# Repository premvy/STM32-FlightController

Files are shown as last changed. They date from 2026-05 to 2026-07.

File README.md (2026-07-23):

# ⚡️Custom STM32  Flight Controller

## Description 
This project is a custom designed, two layer flight controller built to serve as the central brain for a drone prototype. The board is driven by an STM32F722RET6 microcontroller, providing the high-speed processing headroom required for low latency PID loops. The hardware stack features an ICM-42688 6-axis IMU, a BMP580 barometer for precision altitude hold, and a dedicated microSD slot for high rate Blackbox data logging. Power delivery is managed through a modern USB-C interface, paired with a BQ series battery management IC and a clean 5V buck-boost circuit to safely drive servos and ESCs. Beyond just getting a vehicle in the air, this board was designed to push a concept from a raw schematic into a fully manufactured physical product.

## PCB design 





_Custom PCB routed in Kicad_

## Schematic



**Hardware Specs:**
* **MCU:** STM32F722RETx clocked by a 25MHz external crystal.
* **Sensors:** ICM-42688 (6-axis IMU) and BMP580 (Barometer).
* **Power:** USB-C connectivity, BQ-series battery charging, a clean 3.3V logic rail, and a 5V buck-boost rail for servos and ESCs.
* **Data Logging:** Dedicated 4-bit microSD slot for high-speed flight recording.
* **I/O:** 3-pin PWM motor headers and hardware `BOOT` / `RESET` buttons.

[View the Bill of Materials (BOM)](./production/bom.md)

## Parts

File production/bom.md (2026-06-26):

## Bill of Materials

| Designator | Footprint | Qty | Value | LCSC Part # | Unit Price (USD) | Ext. Price (USD) |
|---|---|---|---|---|---|---|
| C1, C29, C30, C31 | 0402 | 4 | 1uF | C52923 | 0.005 | 0.02 |
| C10, C16, C19, C20, C21, C22, C24, C25, C26, C27, C37 | 0201 | 11 | 100nF | C76934 | 0.002 | 0.02 |
| C11, C2, C6, C9 | 0603 | 4 | 10uF | C19702 | 0.016 | 0.06 |
| C12, C13, C14 | 0805 | 3 | 22uF | C45783 | 0.058 | 0.18 |
| C15 | 0603 | 1 | 2.2uF | C23630 | 0.009 | 0.01 |
| C17, C18 | 0402 | 2 | 22uF | C415703 | 0.088 | 0.18 |
| C23 | 0201 | 1 | 2.2uF | C318539 | 0.014 | 0.01 |
| C28 | 0402 | 1 | 100nF | C1525 | 0.002 | 0.01 |
| C3 | 0402 | 1 | 44uF* | C19702 | 0.016 | 0.02 |
| C32, C4 | 0201 | 2 | 10uF | (DigiKey) | 0.020 | 0.04 |
| C33, C34 | 0201 | 2 | 20pF | C325444 | 0.002 | 0.01 |
| C35, C36 | 0201 | 2 | 6.8pF | C85916 | 0.002 | 0.01 |
| C5 | 0402 | 1 | 47nF | C82219 | 0.003 | 0.01 |
| C7, C8 | 0805 | 2 | 10uF | C440198 | 0.038 | 0.08 |
| CARD1 | TF-SMD_TF-01A | 1 | TF-01A microSD | C91145 | 0.190 | 0.19 |
| D1 | 0402 | 1 | LED | C965793 | 0.008 | 0.01 |
| J1 | TerminalBlock 2P P2.54mm | 1 | Screw Terminal | (DigiKey 282834-2) | 1.870 | 1.87 |
| J2, J3 | PinHeader 1x03 P2.54mm | 2 | Conn_01x03 | (DigiKey) | 0.100 | 0.20 |
| L1 | L2520 | 1 | 1uH | C435392 | 0.450 | 0.45 |
| L2 | IND-SMD L4.0xW4.0 | 1 | 1.5uH | C3033018 | 1.370 | 1.37 |
| L3 | IND-SMD L3.0xW3.0 | 1 | 5.6uH | C18236327 | 0.560 | 0.56 |
| L4 | L0603 | 1 | 600R ferrite | C141723 | 0.150 | 0.15 |
| R1, R2 | 0201 | 2 | 5.1k | C270344 | 0.001 | 0.01 |
| R10 | 0201 | 1 | 383 | (DigiKey) | 0.034 | 0.03 |
| R11, R12, R13, R16-R22, R3-R7 | 0201 | 15 | 10K | C7467266 | 0.001 | 0.02 |
| R14 | 0402 | 1 | 100K | C25741 | 0.005 | 0.01 |
| R15 | 0201 | 1 | 22.1K | C384418 | 0.010 | 0.01 |
| R8 | 0201 | 1 | 5.23K | C332546 | 0.011 | 0.01 |
| R9 | 0201 | 1 | 30.1K | (DigiKey) | 0.034 | 0.03 |
| SW1, SW2 | SW-SMD L3.9xW3.0 | 2 | TS-1088-AR02016 | C720477 | 0.120 | 0.24 |
| U1 | LGA-10 BMP580 | 1 | BMP580 baro | C22391138 | 2.500 | 2.50 |
| U2 | LQFP-64 | 1 | STM32F722RETx | C118207 | 4.160 | 4.16 |
| U3 | LGA-14 | 1 | ICM-45686 IMU | C22459454 | 9.760 | 9.76 |
| U4 | VQFN-15 | 1 | TPS63070RNMR | C109322 | 3.500 | 3.50 |
| U5 | VFQFPN-24 | 1 | BQ25883RGER | C544362 | 2.800 | 2.80 |
| U6 | SOT-23-6 | 1 | LMR51430 | C5219261 | 0.550 | 0.55 |
| USB1 | USB-C 16P 2MD | 1 | Type-C | C2765186 | 0.400 | 0.40 |
| X1 | CRYSTAL-SMD 4P | 1 | X322525MOB4SI 25MHz | C9006 | 0.350 | 0.35 |
| X2 | FC-135R | 1 | Q13FC1350000400 32.768kHz | C32346 | 0.300 | 0.30 |
| | | | | | **Component subtotal** | **30.43** |

## Full Prototype Cost (JLCPCB)

- **PCB:** $18.46
- **PCBA: $154.29**, broken into:
  - Setup fee: $25.56
  - Stencil: $8.21
  - Components (32): $62.66
  - Feeder loading: $48.96
  - SMT assembly: $1.85
  - X-ray inspection: $6.56
  - Packaging: $0.49
- **Total: $172.75** (before shipping &rarr; ~$200 delivered)

> **Note on scaling:** This is a run cost, not a per-unit cost. Roughly **$82.73** of the total is one-time non-recurring setup &mdash; setup fee ($25.56), stencil ($8.21), and feeder loading ($48.96) &mdash; which does not repeat on follow-up orders. The two-board minimum is why the $62.66 component line is ~2x the $30.43 per-board BOM subtotal above. The marginal cost of additional boards is substantially lower once the line is set up.

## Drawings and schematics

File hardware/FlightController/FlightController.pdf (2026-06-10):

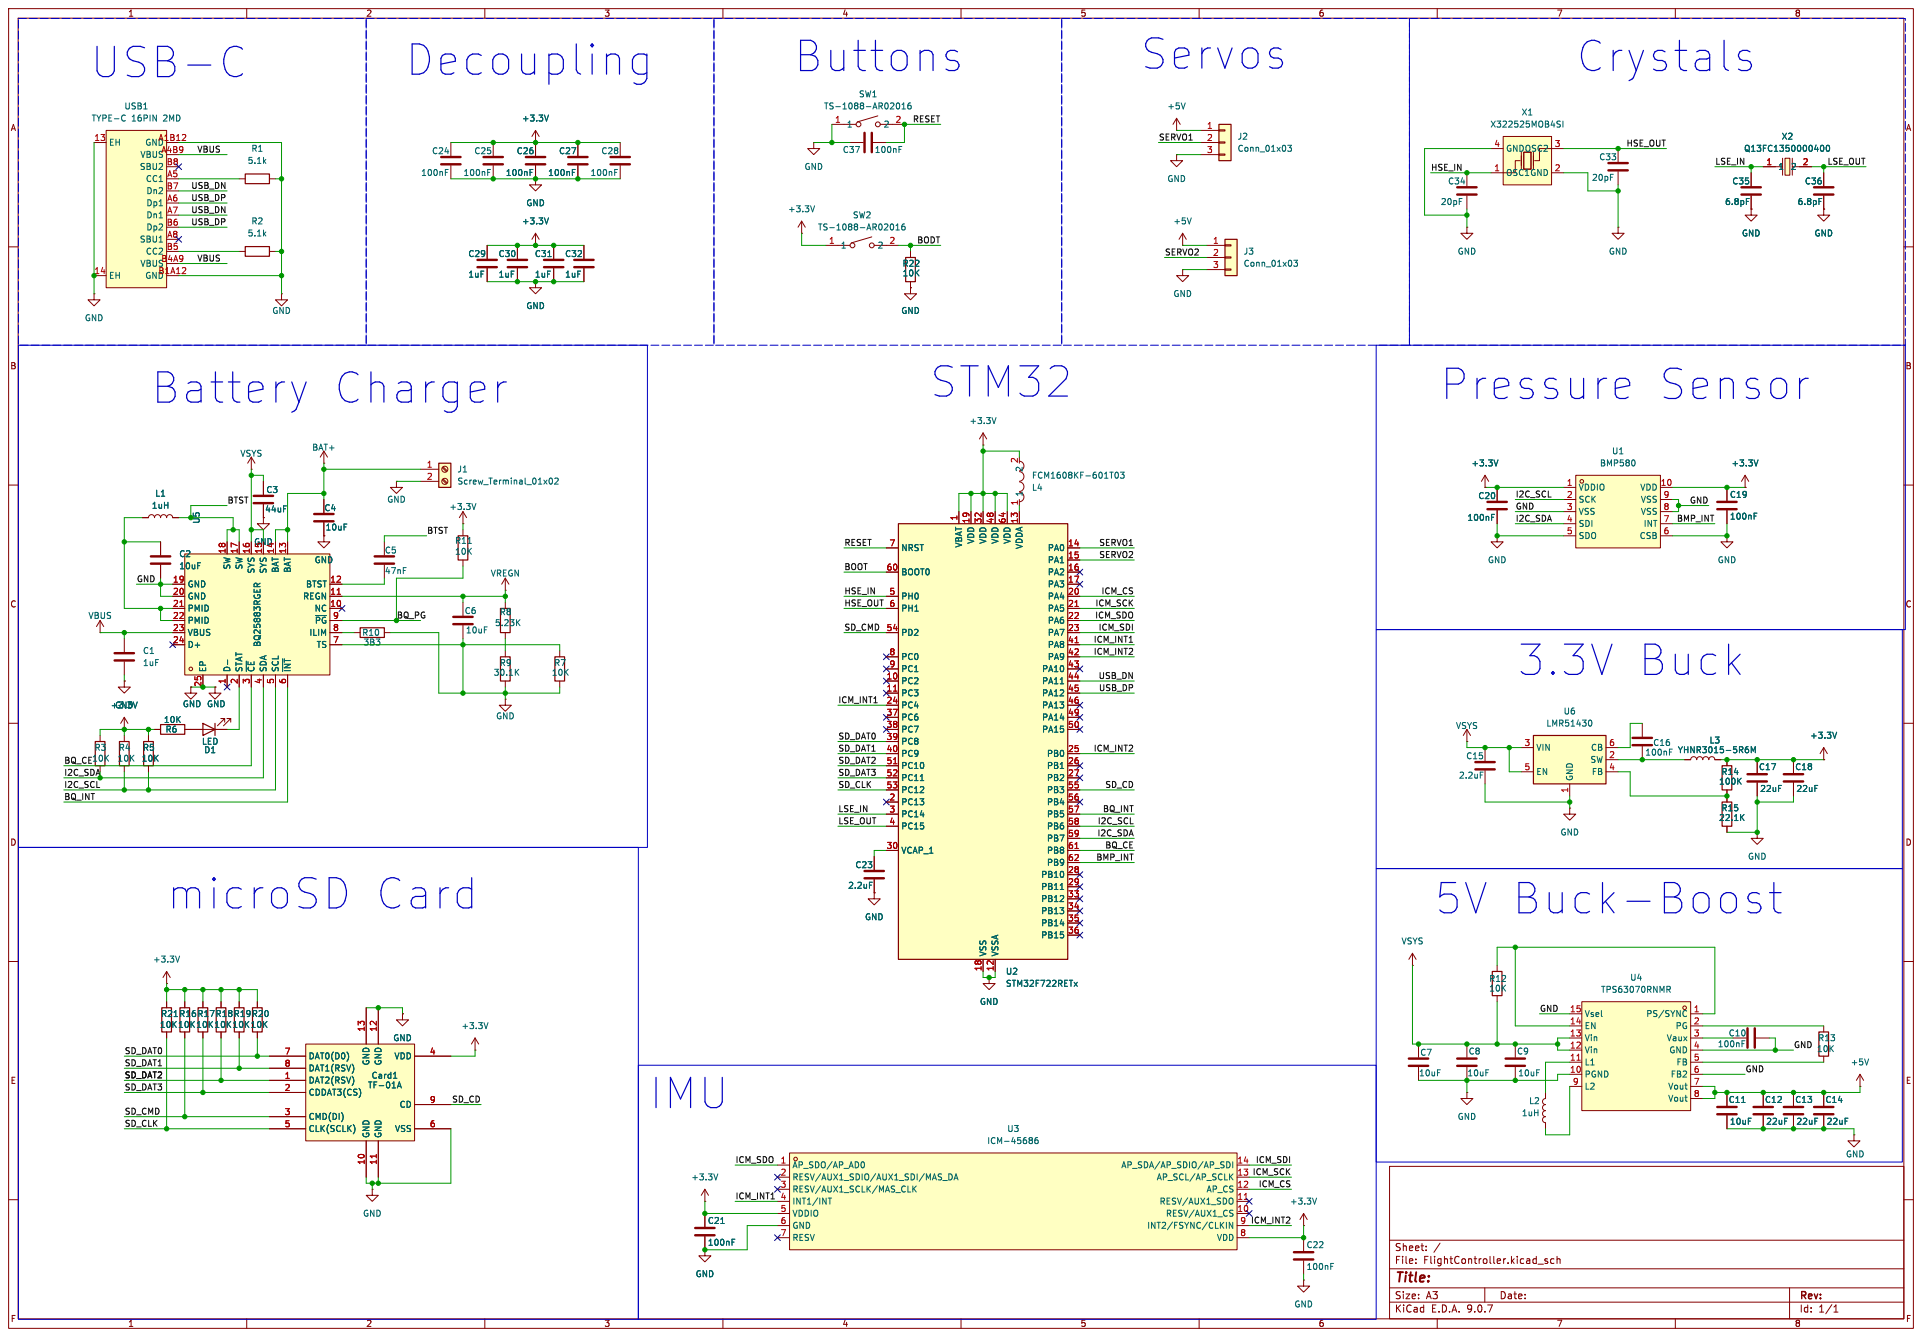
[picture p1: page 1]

5 ~{INT} 6 D+ 24 TS 7 VBUS 23 ILIM 8 PMID 22 ~{PG}9 PMID 21 NC 10 GND 20 REGN 11 GND 19 BTST 12 SW 18 SW 17 SYS 16 SYS 15 BAT 14 BAT 13 U5 BQ25883RGER GND GND

1 VDD 19 VDD 32 VSS 18 VDD 48 VSSA 12 VDD 64 VDDA 13 PA0 14 PA1 15 PA2 16 PA3 17 PA4 20 PA5 21 PA6 22 PA7 23 PA8 41 PA9 42 PA10 43 PA11 44 PA12 45 PA13 46 PA14 49 PA15 50 PB0 25 PB1 26 PB2 27 PB3 55 PB4 56 PB5 57 PB6 58 PB7 59 PB8 61 PB9 62 PB10 28 PB11 29 PB12 33 PB13 34 PB14 35 PB15 36 GND

1 VDD 19 VDD 32 VSS 18 VDD 48 VSSA 12 VDD 64 VDDA 13 PA0 14 PA1 15 PA2 16 PA3 17 PA4 20 PA5 21 PA6 22 PA7 23 PA8 41 PA9 42 PA10 43 PA11 44 PA12 45 PA13 46 PA14 49 PA15 50 PB0 25 PB1 26 PB2 27 PB3 55 PB4 56 PB5 57 PB6 58 PB7 59 PB8 61 PB9 62 PB10 28 PB11 29 PB12 33 PB13 34 PB14 35 PB15 36 U2STM32F722RETx VSYS

5 ~{INT} 6 D+ 24 TS 7 VBUS 23 ILIM 8 PMID 22 ~{PG}9 PMID 21 NC 10 GND 20 REGN 11 GND 19 BTST 12 SW 18 SW 17 SYS 16 SYS 15 BAT 14 BAT 13 GND C2
VSYS C2

6 Vout 7 Vout 8 Vsel 15 EN 14 Vin 13 Vin 12

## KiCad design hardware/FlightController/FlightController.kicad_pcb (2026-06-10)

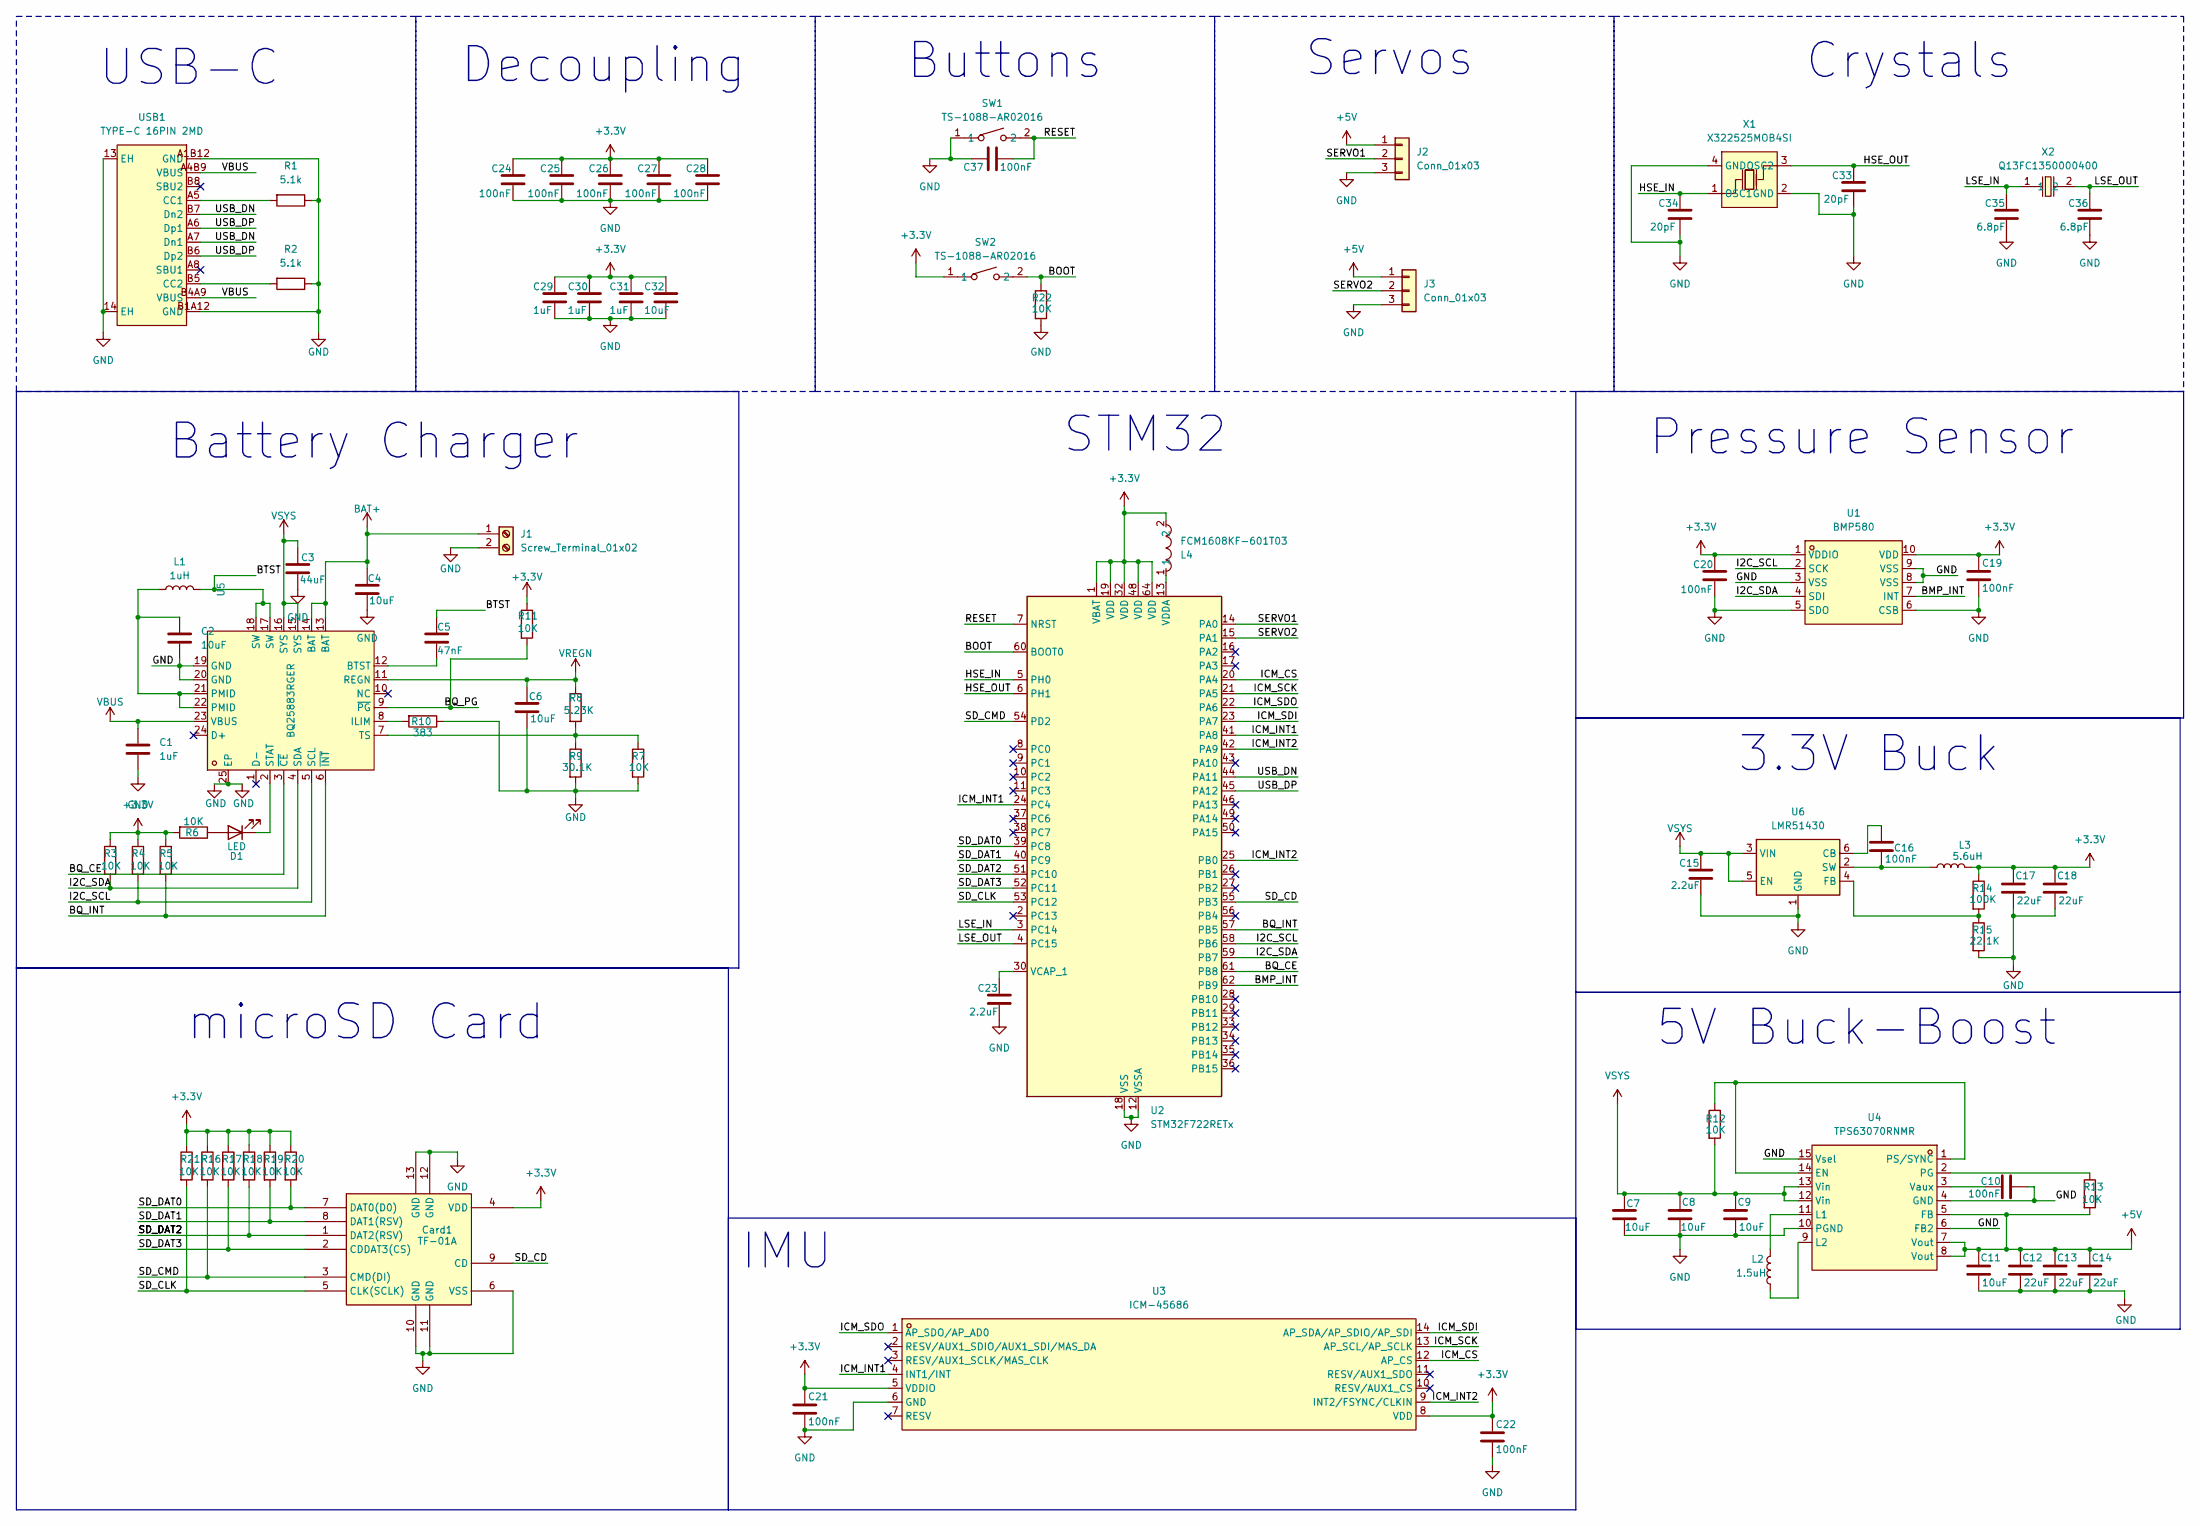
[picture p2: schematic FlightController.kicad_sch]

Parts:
C1, C29, C30, C31: 1uF; C_0402_1005Metric
C2, C6, C9, C11: 10uF; C_0603_1608Metric
C3: 44uF; C_0402_1005Metric
C4, C32: 10uF; C_0201_0603Metric
C5: 47nF; C_0402_1005Metric
C7, C8: 10uF; C_0805_2012Metric
C10, C16, C19, C20, C21, C22, C24, C25, C26, C27, C37: 100nF; C_0201_0603Metric
C12, C13, C14: 22uF; C_0805_2012Metric
C15: 2.2uF; C_0603_1608Metric
C17, C18: 22uF; C_0402_1005Metric
C23: 2.2uF; C_0201_0603Metric
C28: 100nF; C_0402_1005Metric
C33, C34: 20pF; C_0201_0603Metric
C35, C36: 6.8pF; C_0201_0603Metric
Card1: TF-01A; TF-SMD_TF-01A; MPN TF-01A; LCSC Part C91145
D1: LED; LED_0402_1005Metric
J1: Screw_Terminal_01x02; TerminalBlock_Xinya_XY308-2.54-2P_1x02_P2.54mm_Horizontal
J2, J3: Conn_01x03; PinHeader_1x03_P2.54mm_Vertical
L1: 1uH; L2520
L2: 1.5uH; IND-SMD_L4.0-W4.0-A
L3: 5.6uH; IND-SMD_L3.0-W3.0
L4: FCM1608KF-601T03; L0603; MPN FCM1608KF-601T03; LCSC Part C141723
R1, R2: 5.1k; R_0201_0603Metric
R3, R4, R5, R6, R7, R11, R12, R13, R16, R17, R18, R19, R20, R21, R22: 10K; R_0201_0603Metric
R8: 5.23K; R_0201_0603Metric
R9: 30.1K; R_0201_0603Metric
R10: 383; R_0201_0603Metric
R14: 100K; R_0402_1005Metric
R15: 22.1K; R_0201_0603Metric
SW1, SW2: TS-1088-AR02016; SW-SMD_L3.9-W3.0-P4.45; MPN TS-1088-AR02016; LCSC Part C720477
U1: BMP580; LGA-10_L2.0-W2.0-P0.50-TL_BMP580; MPN BMP580; LCSC Part C22391138
U2: STM32F722RETx; LQFP-64_10x10mm_P0.5mm
U3: ICM-45686; LGA-14_L3.0-W2.5-P0.50-TL; MPN ICM-45686; LCSC Part C22459454
U4: TPS63070RNMR; VQFN-15_L3.0-W2.5-P0.50-BL; MPN TPS63070RNMR; LCSC Part C109322
U5: BQ25883RGER; VFQFPN-24_L4.0-W4.0-P0.50-BL-EP2.8; MPN BQ25883RGER; LCSC Part C544362
U6: LMR51430; SOT-23-6
USB1: TYPE-C 16PIN 2MD; USB-C-SMD_TYPE-C-16PIN-2MD-073; MPN TYPE-C 16PIN 2MD(073); LCSC Part C2765186
X1: X322525MOB4SI; CRYSTAL-SMD_4P-L3.2-W2.5-BL; MPN X322525MOB4SI; LCSC Part C9006
X2: Q13FC1350000400; FC-135R_L3.2-W1.5; MPN Q13FC13500004; LCSC Part C32346

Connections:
+3.3V: C17.1, C18.1, C19.1, C20.1, C21.1, C22.1, C24.1, C25.1, C26.1, C27.1, C28.1, C29.1, C30.1, C31.1, C32.1, Card1.4 (VDD), L3.2, L4.2, R3.1, R4.1, R5.1, R6.2, R11.1, R14.1, R16.1, R17.1, R18.1, R19.1, R20.1, R21.1, SW2.1, U1.1 (VDDIO), U1.10 (VDD), U2.1 (VBAT), U2.19 (VDD), U2.32 (VDD), U2.48 (VDD), U2.64 (VDD), U3.5 (VDDIO), U3.8 (VDD)
+5V: C11.1, C12.1, C13.1, C14.1, J2.1, J3.1, R13.2, U4.5 (FB), U4.7 (Vout), U4.8 (Vout)
/BMP_INT: U1.7 (INT), U2.62 (PB9)
/BOOT: R22.1, SW2.2, U2.60 (BOOT0)
/BQ_CE: U2.61 (PB8), U5.3 (~CE)
/BQ_INT: R5.2, U2.57 (PB5), U5.6 (~INT)
/BQ_PG: R11.2, U5.9 (~PG)
/BTST: C5.1, L1.2, U5.17 (SW), U5.18 (SW)
/HSE_IN: C34.1, U2.5 (PH0), X1.1 (OSC1)
/HSE_OUT: C33.1, U2.6 (PH1), X1.3 (OSC2)
/I2C_SCL: R4.2, U1.2 (SCK), U2.58 (PB6), U5.5 (SCL)
/I2C_SDA: R3.2, U1.4 (SDI), U2.59 (PB7), U5.4 (SDA)
/ICM_CS: U2.20 (PA4), U3.12 (AP_CS)
/ICM_INT1: U2.24 (PC4), U2.41 (PA8), U3.4 (INT1/INT)
/ICM_INT2: U2.25 (PB0), U2.42 (PA9), U3.9 (INT2/FSYNC/CLKIN)
/ICM_SCK: U2.21 (PA5), U3.13 (AP_SCL/AP_SCLK)
/ICM_SDI: U2.23 (PA7), U3.14 (AP_SDA/AP_SDIO/AP_SDI)
/ICM_SDO: U2.22 (PA6), U3.1 (AP_SDO/AP_AD0)
/LSE_IN: C35.1, U2.3 (PC14), X2.1
/LSE_OUT: C36.1, U2.4 (PC15), X2.2
/RESET: C37.2, SW1.2, U2.7 (NRST)
/SD_CD: Card1.9 (CD), U2.55 (PB3)
/SD_CLK: Card1.5 (CLK(SCLK)), R21.2, U2.53 (PC12)
/SD_CMD: Card1.3 (CMD(DI)), R16.2, U2.54 (PD2)
/SD_DAT0: Card1.7 (DAT0(D0)), R20.2, U2.39 (PC8)
/SD_DAT1: Card1.8 (DAT1(RSV)), R19.2, U2.40 (PC9)
/SD_DAT2: Card1.1 (DAT2(RSV)), R18.2, U2.51 (PC10)
/SD_DAT3: Card1.2 (CDDAT3(CS)), R17.2, U2.52 (PC11)
/SERVO1: J2.2, U2.14 (PA0)
/SERVO2: J3.2, U2.15 (PA1)
/USB_DN: U2.44 (PA11), USB1.A7 (Dn1), USB1.B7 (Dn2)
/USB_DP: U2.45 (PA12), USB1.A6 (Dp1), USB1.B6 (Dp2)
BAT+: C4.1, J1.1, U5.13 (BAT), U5.14 (BAT)
GND: C1.2, C2.2, C3.2, C4.2, C6.2, C7.2, C8.2, C9.2, C10.1, C11.2, C12.2, C13.2, C14.2, C15.2, C17.2, C18.2, C19.2, C20.2, C21.2, C22.2, C23.2, C24.2, C25.2, C26.2, C27.2, C28.2, C29.2, C30.2, C31.2, C32.2, C33.2, C34.2, C35.2, C36.2, C37.1, Card1.6 (VSS), Card1.10 (GND), Card1.11 (GND), Card1.12 (GND), Card1.13 (GND), J1.2, J2.3, J3.3, R1.1, R2.1, R7.2, R9.2, R10.1, R15.2, R22.2, SW1.1, U1.3 (VSS), U1.5 (SDO), U1.6 (CSB), U1.8 (VSS), U1.9 (VSS), U2.12 (VSSA), U2.18 (VSS), U2.31 (VSS), U2.47 (VSS), U2.63 (VSS), U3.6 (GND), U4.4 (GND), U4.6 (FB2), U4.10 (PGND), U4.15 (Vsel), U5.19 (GND), U5.20 (GND), U5.25 (EP), U6.1 (GND), USB1.13 (EH), USB1.14 (EH), USB1.A1B12 (GND), USB1.B1A12 (GND), X1.2 (GND), X1.4 (GND)
unnamed: C2.1, L1.1, U5.21 (PMID), U5.22 (PMID)
unnamed: D1.2 (A), R6.1
unnamed: D1.1 (K), U5.2 (STAT)
unnamed: C23.1, U2.30 (VCAP_1)
unnamed: L4.1, U2.13 (VDDA)
unnamed: R12.1, U4.1 (PS/SYNC), U4.14 (EN)
unnamed: L2.2, U4.11 (L1)
unnamed: L2.1, U4.9 (L2)
unnamed: R13.1, U4.2 (PG)
unnamed: C10.2, U4.3 (Vaux)
unnamed: C5.2, U5.12 (BTST)
unnamed: R10.2, U5.8 (ILIM)
unnamed: R7.1, R8.2, R9.1, U5.7 (TS)
unnamed: C16.2, U6.6 (CB)
unnamed: R14.2, R15.1, U6.4 (FB)
unnamed: C16.1, L3.1, U6.2 (SW)
unnamed: R1.2, USB1.A5 (CC1)
unnamed: R2.2, USB1.B5 (CC2)
VBUS: C1.1, U5.23 (VBUS), USB1.A4B9 (VBUS), USB1.B4A9 (VBUS)
VREGN: C6.1, R8.1, U5.11 (REGN)
VSYS: C3.1, C7.1, C8.1, C9.1, C15.1, R12.2, U4.12 (Vin), U4.13 (Vin), U5.15 (SYS), U5.16 (SYS), U6.3 (VIN), U6.5 (EN)

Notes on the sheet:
Buttons
USB-C
IMU
STM32
Crystals
Pressure Sensor
Servos
Decoupling
microSD Card
3.3V Buck
Battery Charger
5V Buck-Boost

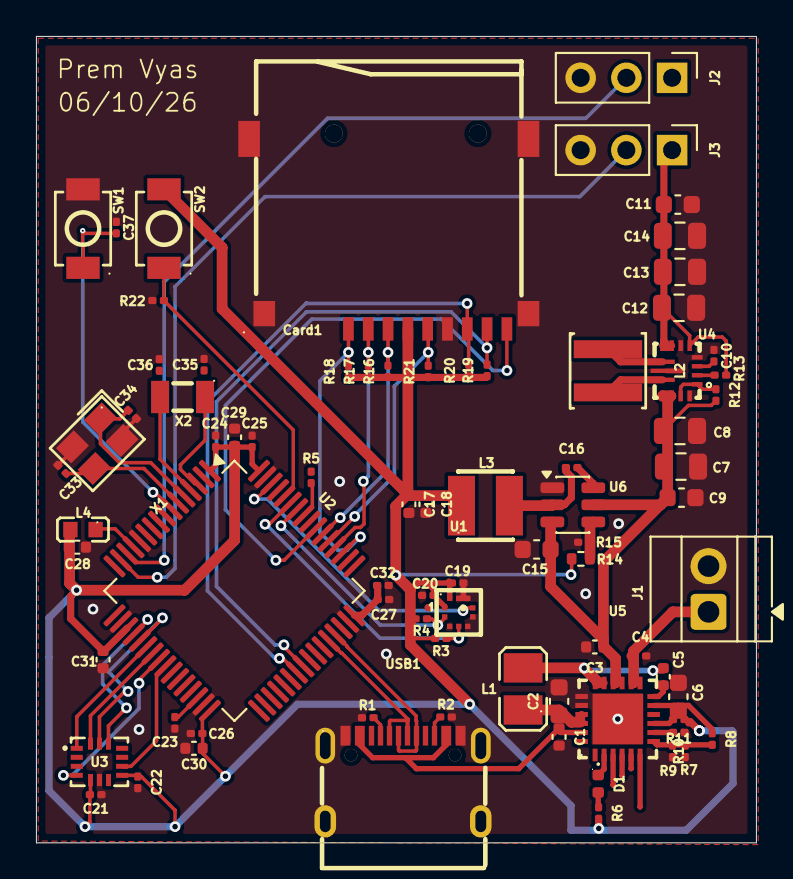
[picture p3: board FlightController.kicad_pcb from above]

Board: 2 copper layers, 40.0 x 44.8 mm, 79 parts (0 on the bottom side), 55 nets.

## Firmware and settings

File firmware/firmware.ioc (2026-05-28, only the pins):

Mcu.UserName=STM32F722RETx
PA0-WKUP.Signal=S_TIM2_CH1_ETR
PA1.Signal=S_TIM2_CH2
PA11.Signal=USB_OTG_FS_DM
PA12.Signal=USB_OTG_FS_DP
PA4.Signal=SPI1_NSS
PA5.Signal=SPI1_SCK
PA6.Signal=SPI1_MISO
PA7.Signal=SPI1_MOSI
PB0.GPIO_Label=ICM_INT2
PB0.Signal=GPXTI0
PB3.GPIO_Label=SD_CS
PB3.Signal=GPIO_Input
PB5.GPIO_Label=BQ_INT
PB5.Signal=GPXTI5
PB6.Signal=I2C1_SCL
PB7.Signal=I2C1_SDA
PB8.GPIO_Label=BQ_CE
PB8.Signal=GPIO_Output
PB9.GPIO_Label=BMP_INT
PB9.Signal=GPXTI9
PC10.Signal=SDMMC1_D2
PC11.Signal=SDMMC1_D3
PC12.Signal=SDMMC1_CK
PC14-OSC32_IN.Signal=RCC_OSC32_IN
PC15-OSC32_OUT.Signal=RCC_OSC32_OUT
PC4.GPIO_Label=ICM_INT1
PC4.Signal=GPXTI4
PC8.Signal=SDMMC1_D0
PC9.Signal=SDMMC1_D1
PD2.Signal=SDMMC1_CMD
PH0-OSC_IN.Signal=RCC_OSC_IN
PH1-OSC_OUT.Signal=RCC_OSC_OUT

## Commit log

2026-05-28 Add schematic section to README
    Added a new section for the schematic in the README.
2026-05-28 Update Schematic section header in README
2026-05-28 Add schematic image to README
2026-05-28 Update schematic image in README
2026-06-10 Add 3D model section and remove BOM
    Updated the README to include a 3D model section with images and removed the Bill of Materials.
2026-06-10 Update PCB design images in README
    Added a new image to the PCB design section of the README.
2026-06-26 Revise production BOM with updated components
    Updated BOM with new component details and pricing.
    [bom.csv]
2026-06-26 Enhance BOM with unit and extended price columns
    Updated BOM to include unit and extended prices for components.
    [bom.csv]
2026-06-26 Restore Bill of Materials and cost details
    Restored the Bill of Materials and Full Prototype Cost sections with updated formatting and details.
2026-07-23 Remove Bill of Material mention from README
    Removed the line about the Bill of Material from the README.
